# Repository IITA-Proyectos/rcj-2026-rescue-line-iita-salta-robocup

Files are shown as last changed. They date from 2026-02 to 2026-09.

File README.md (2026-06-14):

# RescueBot IITA - RoboCupJunior Rescue Line 2026

<p align="center">
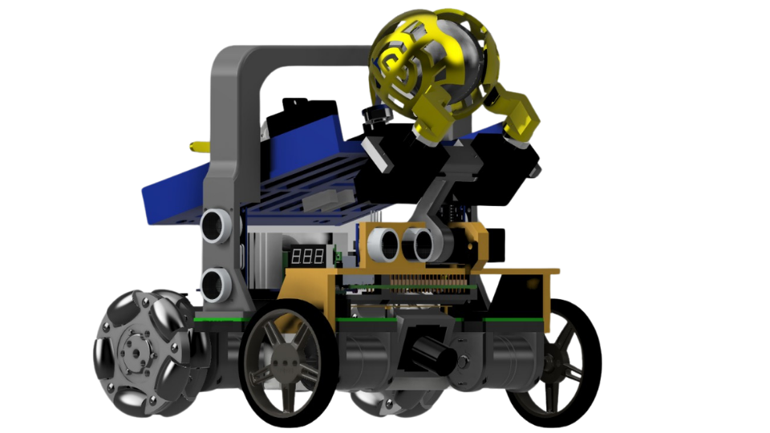
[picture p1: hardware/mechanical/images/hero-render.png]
RescueBot IITA render
  
</p>

<p align="center">
  <strong>Autonomous Rescue Line robot by IITA Salta, Argentina.</strong><br>
  Built for line following, obstacle handling, victim detection, rescue-zone collection, sorting, deposit and evacuation-zone exit.
</p>

<p align="center">
  
  
  
  
  
  
  
  
</p>

## About The Competition

<p align="center">
  <i>
    RoboCupJunior Rescue Line challenges teams to build a fully autonomous robot that can navigate a disaster-inspired course, follow lines, handle obstacles, identify victims, move them to safe evacuation zones and leave the rescue area without human assistance.
  </i>
</p>

<p align="center">
  <a href="https://junior.robocup.org/">RoboCupJunior</a> |
  <a href="https://junior.robocup.org/rcj-rescue-line/">Rescue Line</a> |
  <a href="https://rescue.rcj.cloud/documents">Official Rescue Documents</a>
</p>

## About The Robot

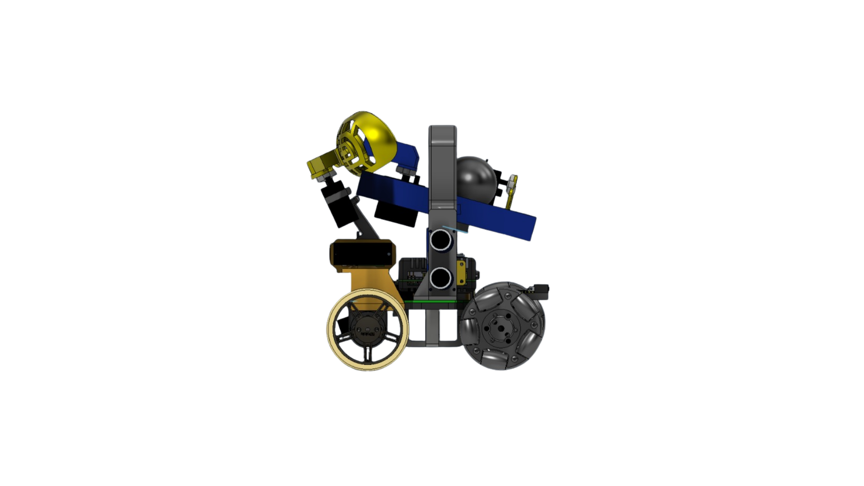
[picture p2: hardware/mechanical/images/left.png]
Left CAD view of RescueBot IITA


RescueBot IITA is a fully autonomous RoboCupJunior Rescue Line robot developed by students from the Instituto de Innovacion y Tecnologia Aplicada (IITA), Salta, Argentina. The robot combines a custom 3D-printed Fusion 360 chassis, a five-servo rescue mechanism, a custom electronics stack, a Raspberry Pi 4B vision system and a Teensy 4.1 real-time controller.

The robot was built to complete the full Rescue Line mission as an integrated system: line following, green-marker decisions, obstacle handling, rescue-zone entry, victim collection, sorting, deposit and evacuation-zone exit. The Raspberry Pi handles vision and high-level decisions, while the Teensy keeps movement, sensors, servos and safety routines deterministic.

<br clear="left">

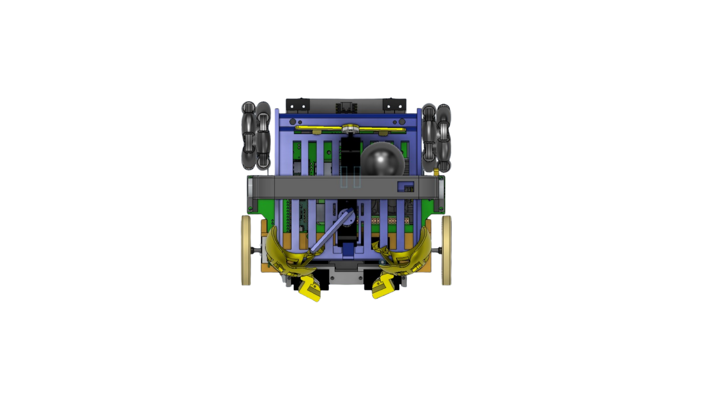
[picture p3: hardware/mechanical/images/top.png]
Top CAD view of RescueBot IITA


The mechanical design focuses on serviceability. The chassis is compact, printable and organized in layers: drivetrain below, electronics in the middle and the rescue mechanism above/front. The project also keeps the engineering trail visible: CAD files, electronics references, firmware, Raspberry Pi code, AI model evolution, test logs and the Team Description Paper are all kept in the repository.

<br clear="right">

## What The Robot Does

| Mission stage | How RescueBot handles it |
|---|---|
| Line course | Raspberry Pi camera pipeline tracks the black line, green markers, red stop line and silver rescue-zone entry. |
| Motion control | Teensy 4.1 executes motor control, encoder movements, IMU turns, distance sensing and safety behavior. |
| Obstacle handling | Ultrasonic and ToF sensors support obstacle detection, wall approach and rescue-zone alignment. |
| Rescue-zone perception | YOLOv8n/TFLite detects black victims, silver victims and high red/green deposit zones. |
| Victim handling | A five-servo claw collects, lifts, sorts, stores and deposits victims. |
| Reliability | Serial protocol guards, timeout fixes, APDS9960 floor sensing and documented tests target competition robustness. |

## Robot At A Glance

| Area | Current design |
|---|---|
| Robot name | Jesus |
| Competition | RoboCupJunior Rescue Line 2026 |
| Main compute | Raspberry Pi 4B |
| Real-time control | Teensy 4.1 with Arduino/PlatformIO |
| Vision stack | OpenCV + YOLOv8n exported to TFLite |
| AI classes | `negro`, `plateado`, `rojo_alto`, `verde_alto` |
| CAD | Fusion 360, editable `.f3z` assembly |
| Actuation | Four encoder motors + five clutch servos |
| Sensors | Wide camera, BNO055, VL53L0X, HC-SR04, APDS9960 |
| Measured mass | 1404 g |
| CAD envelope | 157.189 mm L x 176.913 mm W x 176.239 mm H |

## Visual Tour

<table>
  <tr>
    <td align="center">Left side CAD view<br><strong>Left</strong></td>
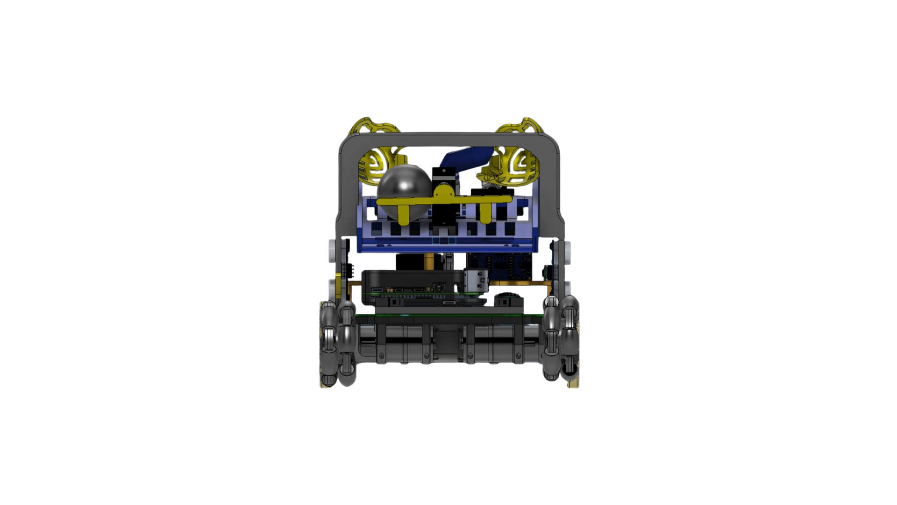
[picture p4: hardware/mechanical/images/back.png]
Back CAD view
    <td align="center"><br><strong>Back</strong></td>
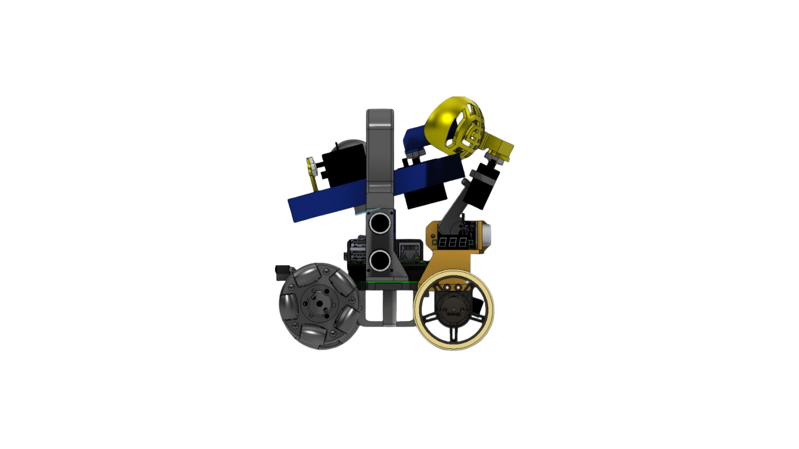
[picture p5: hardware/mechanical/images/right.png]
Right side CAD view
    <td align="center"><br><strong>Right</strong></td>
  </tr>
  <tr>
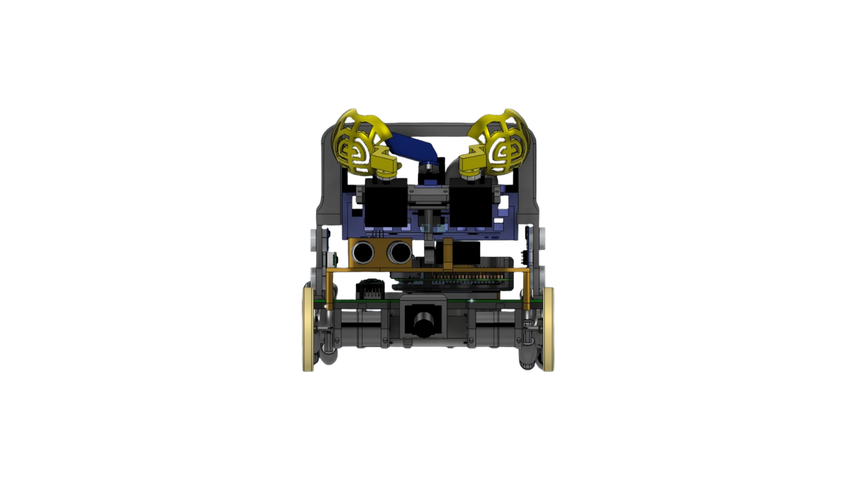
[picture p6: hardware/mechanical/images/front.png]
Front CAD view
    <td align="center"><br><strong>Front</strong></td>
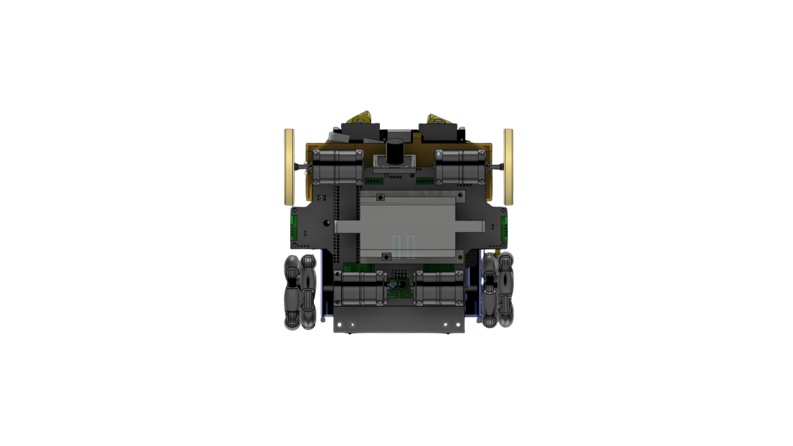
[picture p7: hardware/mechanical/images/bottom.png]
Bottom CAD view
    <td align="center"><br><strong>Bottom</strong></td>
    <td align="center">Top CAD view<br><strong>Top</strong></td>
  </tr>
</table>

More mechanical details are available in [hardware/mechanical](hardware/mechanical/README.md), including the editable Fusion 360 archive [Final_Robot.f3z](hardware/mechanical/Final_Robot.f3z).

## System Architecture

<p align="center">
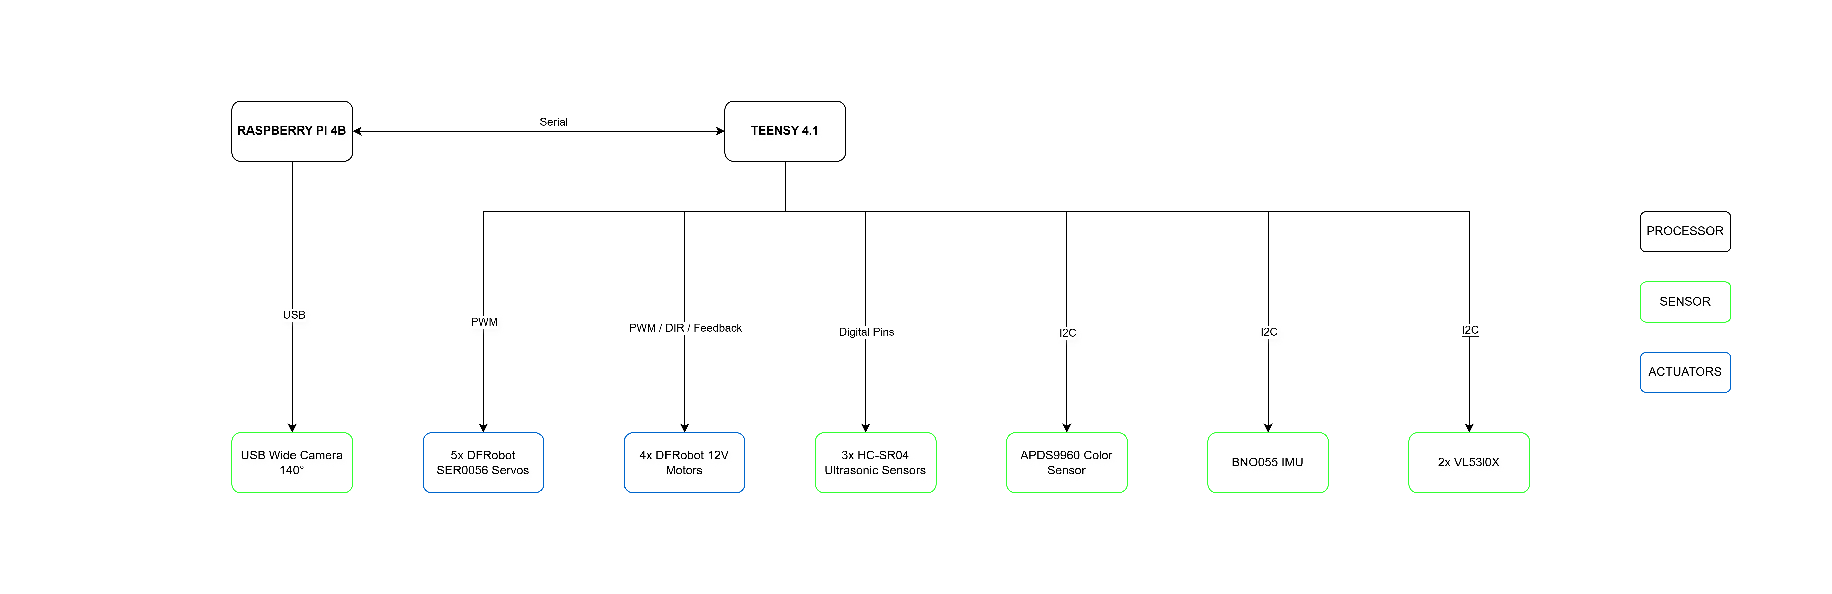
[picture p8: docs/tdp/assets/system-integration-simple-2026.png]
Simplified processor, sensor and actuator integration overview
  
</p>

The robot uses a dual-controller architecture:

- **Raspberry Pi 4B:** camera processing, line tracking, marker detection, rescue-zone AI inference and high-level state decisions.
- **Teensy 4.1:** deterministic motor control, encoders, BNO055 IMU, distance sensors, APDS9960 color sensing, servos, switch/stop behavior and recovery routines.
- **UART protocol:** small 8-byte frames from Raspberry Pi to Teensy plus status bytes from Teensy to Raspberry Pi keep the robot synchronized without a heavy network stack.

## AI And Vision

<table>
  <tr>
    <td align="center" width="25%">
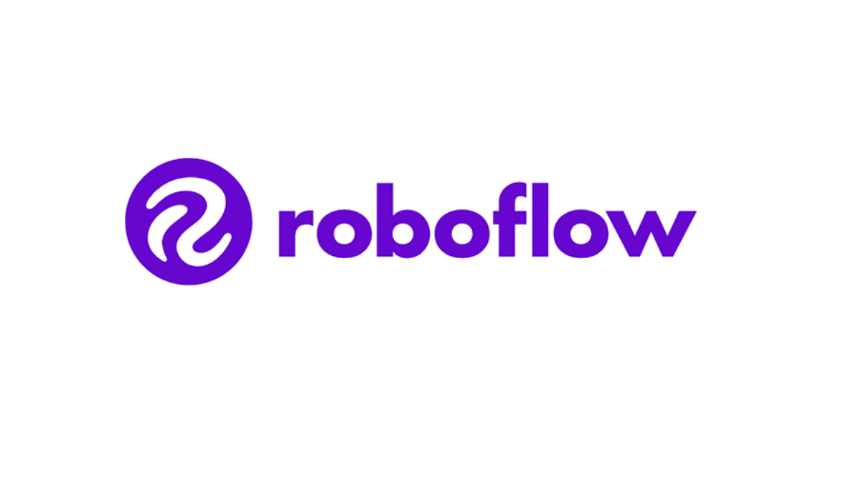
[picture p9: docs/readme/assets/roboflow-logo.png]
Roboflow logo
      <br>
      <strong>Dataset</strong><br>
      Image collection, labeling and class balancing.
    </td>
    <td align="center" width="25%">
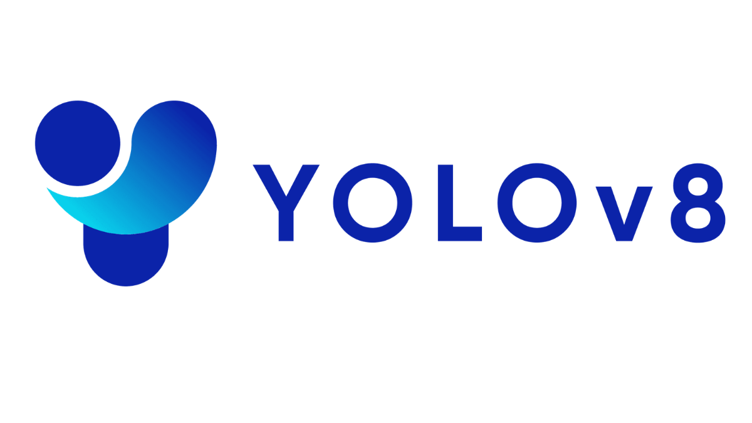
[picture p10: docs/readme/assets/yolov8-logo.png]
YOLOv8 logo
      <br>
      <strong>Detector</strong><br>
      YOLOv8n model for victims and deposit zones.
    </td>
    <td align="center" width="25%">
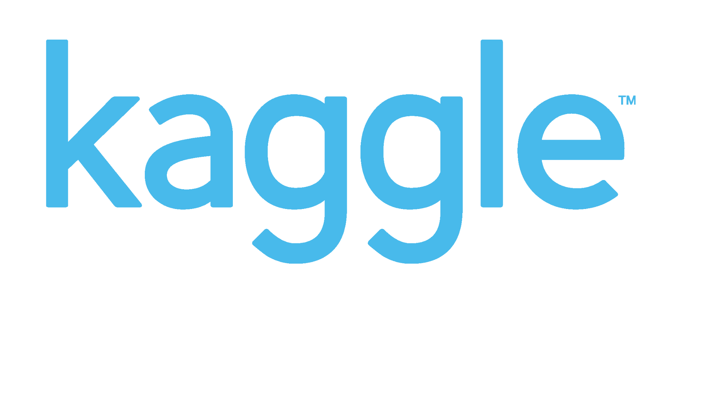
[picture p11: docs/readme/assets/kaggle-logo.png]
Kaggle logo
      <br>
      <strong>Training</strong><br>
      100-epoch training and validation workflow.
    </td>
    <td align="center" width="25%">
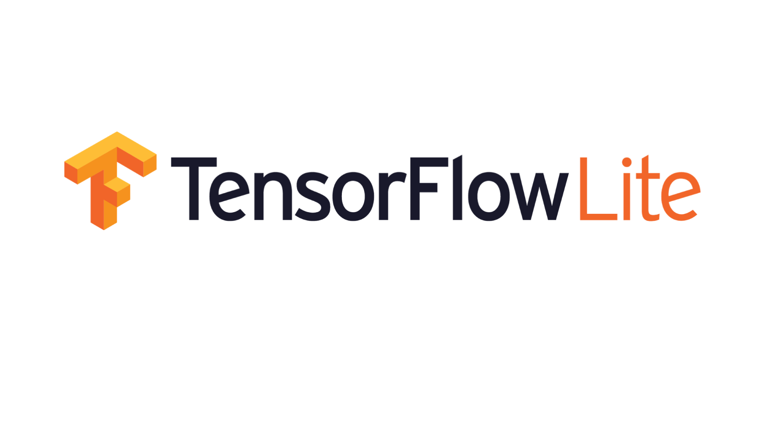
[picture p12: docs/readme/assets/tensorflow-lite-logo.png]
TensorFlow Lite logo
      <br>
      <strong>Deployment</strong><br>
      TFLite inference on the Raspberry Pi 4B.
    </td>
  </tr>
</table>

The rescue-zone detector evolved through several model and dataset versions. The final documented model uses YOLOv8n exported to TFLite with embedded NMS so it can run on the Raspberry Pi 4B without an external AI accelerator.

| Metric | Documented value |
|---|---:|
| Dataset images | 6256 |
| Dataset annotations | 9521 |
| Null examples | 711 |
| Validation precision | 0.971 |
| Validation recall | 0.929 |
| Validation mAP50 | 0.932 |
| Raspberry Pi rescue/deposit loop | 22.25-22.40 FPS |
| Raspberry Pi line loop | 91.33 FPS |

See [software/raspberry/AI](software/raspberry/AI/README.md) and [docs/tdp/roboflow-dataset-status-2026-05-23.md](docs/tdp/roboflow-dataset-status-2026-05-23.md) for the full model history, dataset notes and validation evidence.

## Mechanical Design

<p align="center">
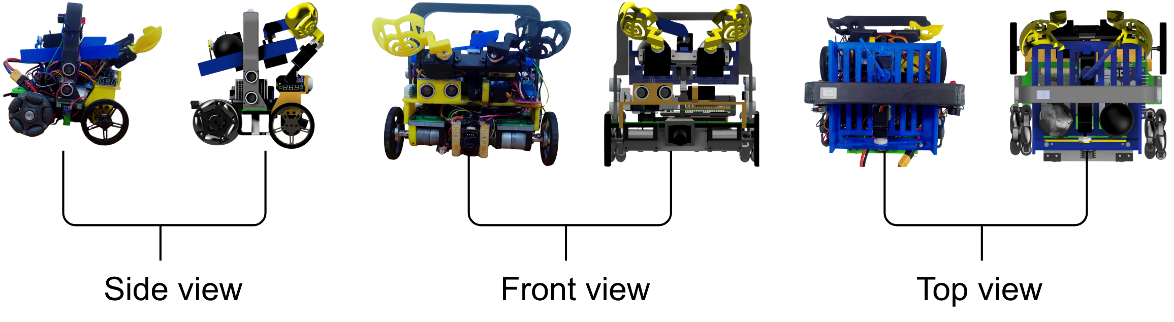
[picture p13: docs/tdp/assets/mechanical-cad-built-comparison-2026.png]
CAD to built robot comparison
  
</p>

The robot is designed as a compact 3D-printed assembly with serviceable mechanical modules:

- Low drivetrain layer with four 12 V encoder motors.
- Electronics and wiring layer for Raspberry Pi, Teensy, PCB and battery access.
- Front rescue mechanism with two gripper servos, lift servo, sorting servo and deposit servo.
- Sensor mounts for camera, ultrasonic sensors, ToF sensors and APDS9960 floor sensing.
- CAD views and editable Fusion 360 source for inspection and future improvements.

## Electronics And Control

The electronics are organized around separated power and control paths:

- 3S 11.1 V LiPo battery.
- 12 V motor path.
- 5 V compute/control rail for Raspberry Pi and Teensy.
- 6.1 V measured servo rail for the rescue mechanism.
- Custom PCB and documented power tree.

Key references:

- [PCB documentation](hardware/electronics/PCB_Main/README.md)
- [Verified component specs](hardware/electronics/PCB_Main/COMPONENT_SPECS_VERIFIED.md)
- [Hardware change notes](hardware/cambios_de_hardware.md)

## Performance Evidence

The repository keeps test logs instead of only final claims. Current documented samples include:

| Test area | Evidence |
|---|---|
| Battery/runtime | 1 h continuous runtime until 10.5 V; 10 min high-stress run without observed reset. |
| Movement | `runDistance()` error around 1-2 cm; IMU turns stop around 1 degree. |
| Vision speed | 91.33 FPS line following; 22.25-22.40 FPS rescue/deposit loop. |
| Pickup/deposit sample | 8/10 pickup attempts; 10/10 deposit attempts. |
| Full-course validation | Recorded run with line, rescue, deposit and evacuation-zone exit after the exit-search correction. |
| Lighting robustness | Anti-flash + AGCWD + final model tested against flashlight stress and colored walls. |

Read the test log in [testing/TEST_LOG.md](testing/TEST_LOG.md). The full-course evidence video referenced by the TDP is available here: [YouTube run video](https://www.youtube.com/watch?v=CPpj4CvyvyA).

## Components

| Subsystem | Main components |
|---|---|
| Compute | Raspberry Pi 4B 8GB, Teensy 4.1 |
| Vision | Wide USB camera, OpenCV, YOLOv8n/TFLite |
| Motion | 4x 12 V 159 RPM encoder motors, fixed wheels, omniwheels |
| Rescue mechanism | 5x DFRobot 2 kg 300 degree clutch servos |
| Distance sensing | HC-SR04 ultrasonic sensors, VL53L0X ToF sensors |
| Orientation and floor sensing | BNO055 IMU, APDS9960 color/proximity sensor |
| Power | 3S 11.1 V LiPo battery, XL4016 5 V rail, MP1584 servo rail |
| Mechanical | Fusion 360 CAD, 3D-printed chassis and custom mounts |

## Repository Map

| Path | Purpose |
|---|---|
| [software/raspberry](software/raspberry/README.md) | Raspberry Pi code for line following, rescue vision, AI inference and serial state handling. |
| [software/teensy/firmware](software/teensy/firmware/) | Teensy 4.1 firmware, PlatformIO config, drivebase, claw and sensor code. |
| [software/raspberry/AI](software/raspberry/AI/README.md) | AI model history, dataset versions and model inspection tools. |
| [hardware/mechanical](hardware/mechanical/README.md) | Fusion 360 CAD, robot views and mechanical source files. |
| [hardware/electronics](hardware/electronics/) | PCB, power tree, datasheets and electronics documentation. |
| [docs/tdp](docs/tdp/) | Team Description Paper, diagrams, evidence summaries and final documentation assets. |
| [testing](testing/README.md) | Test logs and validation records. |
| [research](research/) | Research notes, benchmarks and external references. |
| [project](project/) | Backlog and project-management notes. |

## Quick Start

### Raspberry Pi software

```bash
python -m pip install -r software/raspberry/requirements.txt
```

Main competition code:

```bash
cd software/raspberry/final_rpi
python Main.py
```

### Teensy firmware

Requires [PlatformIO](https://platformio.org/) and the PJRC Teensy loader/toolchain.

```bash
cd software/teensy/firmware
pio run
pio run --target upload
```

### Mechanical CAD

Open the editable Fusion 360 archive:

```text
hardware/mechanical/Final_Robot.f3z
```

## Documentation Highlights

- [Team Description Paper source](docs/tdp/TDP-IITA-2026.md)
- [Technical Poster](docs/poster/Poster%20final.pdf)
- [Code reliability evidence](docs/tdp/code-reliability-evidence-2026.md)
- [Raspberry Pi and YOLO notes](docs/es/yolo-raspberry.md)
- [Raspberry Pi to Teensy communication](docs/es/comunicacion-rpi-teensy.md)
- [Firmware libraries](docs/es/librerias-firmware.md)
- [Contribution guide](CONTRIBUTING.md)

## Useful Links

- [Full-course run video](https://www.youtube.com/watch?v=CPpj4CvyvyA)
- [Mechanical CAD package](hardware/mechanical/README.md)
- [AI model evolution](software/raspberry/AI/README.md)
- [Testing evidence log](testing/TEST_LOG.md)
- [RoboCupJunior Rescue Line](https://junior.robocup.org/rcj-rescue-line/)
- [Official Rescue documents](https://rescue.rcj.cloud/documents)

## Contact And Social Media

<p align="center">
  <a href="https://www.youtube.com/@iita-tecnologia-aplicada" target="_blank">
    
  </a>
  <a href="https://www.tiktok.com/@iita_salta" target="_blank">
    
  </a>
  <a href="https://www.linkedin.com/company/iita---instituto-de-innovaci%C3%B3n-y-tecnolog%C3%ADa-aplicada/posts/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" target="_blank">
    
  </a>
  <a href="https://www.facebook.com/IITARoboticaEducativa" target="_blank">
    
  </a>
  <a href="https://www.instagram.com/iita_salta" target="_blank">
    
  </a>
</p>

## Team

| Role | Member |
|---|---|
| Line-following vision and camera processing | Lucio Saucedo |
| Raspberry Pi integration, AI and electronics | Benjamin Villagran |
| 3D design, Teensy firmware and rescue mechanism | Laureano Monteros |
| Mentor / coach support | Enzo Juarez, Gustavo Viollaz |

**Institution:** Instituto de Innovacion y Tecnologia Aplicada (IITA), Salta, Argentina

**Contact:** rescuebot.salta@gmail.com

## Project Status

This repository is under active 2026 competition development. Current project status and real pending work are tracked through GitHub Issues and the coach/director report in [docs/es/2026-05-31-informe-coach-auditoria-integral.md](docs/es/2026-05-31-informe-coach-auditoria-integral.md). The older [AUDIT-ACTION-PLAN.md](AUDIT-ACTION-PLAN.md) remains available as historical context.

Validation work is documented in [testing/TEST_LOG.md](testing/TEST_LOG.md) and the project backlog.

## License

This project is released under the MIT License. See [LICENSE](LICENSE).

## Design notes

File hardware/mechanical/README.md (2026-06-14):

# Mechanical Design - Fusion 360

This folder contains the current mechanical model of the IITA Salta Rescue Line robot for RoboCup Junior 2026. The main file is the editable Fusion 360 assembly and is used as the reference for the chassis layout, claw mechanism, sensor mounts, electronics placement and mounting points.

## Main File

| File | Description |
|---|---|
| [Final_Robot.f3z](Final_Robot.f3z) | Complete robot file exported from Fusion 360. It includes the final assembly and its associated components. |

## Design Summary

The CAD model groups the main mechanical parts of the robot:

- Main chassis/base of the robot.
- Motor mounts and traction system.
- Front claw with servos for collecting and depositing victims.
- Mounts for distance sensors, camera and lower detection sensors.
- Mounting spaces for the Raspberry Pi, electronics, battery and internal wiring.
- Auxiliary parts for guiding balls/victims and keeping the mechanism compact.

The goal of the design is to keep the robot 3D-printable, easy to disassemble for maintenance and spacious enough for the planned hardware improvements: lower LED for the APDS9960, ESP32 Super Mini communication module, rear limit switches and flexible wiring for claw conductivity detection.

## Robot Views

Save the screenshots exported from Fusion 360 in the [`images/`](images/) folder using these names so GitHub displays them in an organized way.

| View | Suggested file | What it should show |
|---|---|---|
| Left side | `images/left.png` | Traction profile, claw and total height. |
| Back | `images/back.png` | Rear side, wiring space and possible limit switch placement. |
| Right side | `images/right.png` | Opposite profile and assembly symmetry. |
| Front | `images/front.png` | Claw, front sensors and overall width. |
| Bottom | `images/bottom.png` | Lower sensors, APDS9960/LED mount and floor clearance. |
| Top | `images/top.png` | Electronics, battery and chassis layout. |

## Gallery

Left side view

Back view

Right side view

Front view

Bottom view

Top view

## Existing Material

The [`_legacy/CAD/`](_legacy/CAD/) folder keeps the previous robot material:

- Previous screenshots of the model.
- Previous editable file (`Rescue3D.f3d`).
- Historical STLs for the base, mounts, claw, case, fins, camera, ultrasonic sensors and auxiliary parts.

That material remains as reference, but the recommended file for continuing the design is [`Final_Robot.f3z`](Final_Robot.f3z).

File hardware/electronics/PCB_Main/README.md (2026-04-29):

# BOM — Lista de Materiales

## Componentes electrónicos

| Componente | Uso | Cantidad | Proveedor | Link |
|---|---|:---:|---|---|
| USB Wide Camera 140° | Reconocimiento de imagen | 1 | Amazon | [Ver](https://www.amazon.com/dp/B0DR7XXJL1) |
| BNO055 (IMU) | Giros con precisión | 1 | Adafruit | [Ver](https://www.adafruit.com/product/2472) |
| Sensor ToF VL53L0X | Detección de distancia | 2 | MercadoLibre | [Ver](https://articulo.mercadolibre.com.ar/MLA-921894672-gy-53-vl53l0x-modulo-sensor-de-serie-pwm-salida-laser-rango-_JM) |
| Sensor ultrasonido HC-SR04 | Detección de obstáculos | 3 | MercadoLibre | [Ver](https://articulo.mercadolibre.com.ar/MLA-676922257-hc-sr04-sensor-de-distancia-ultrasonico-para-desarrollo-_JM) |
| APDS9960 (color/gestos) | Detección de línea negra luego de obstáculo | 1 | MercadoLibre | [Ver](https://www.mercadolibre.com.ar/sensor-de-colores-gestos-proximidad-rgb-gy-9960-desarrollo/up/MLAU129280454) |
| Raspberry Pi 4 (8GB) | Procesamiento de imagen con Python | 1 | MercadoLibre | [Ver](https://articulo.mercadolibre.com.ar/MLA-935558208-raspberry-pi-4-model-b-8gb-element14-uk-placa-sbc-original-_JM) |
| Teensy 4.1 | Control de sensores, motores y servos | 1 | PJRC | [Ver](https://www.pjrc.com/store/teensy41.html) |

## Componentes mecánicos

| Componente | Uso | Cantidad | Proveedor | Link |
|---|---|:---:|---|---|
| Brushless DC Motor con Encoder 12V 159RPM | Motor | 4 | DFRobot | [Ver](https://www.dfrobot.com/product-1364.html) |
| Servo Clutch 2kg 300° | Activar mecanismos | 5 | DFRobot | [Ver](https://www.dfrobot.com/product-2126.html) |
| Rueda Omniwheel 58mm 12kg | Desplazamientos laterales y mayor tracción | 2 | eBay | [Ver](https://www.ebay.com/itm/155463932973) |
| Ruedas fijas | Desplazamiento frontal | 2 | Pololu | [Ver](https://www.pololu.com/product/1420) |

## Alimentación y reguladores

| Componente | Uso | Cantidad | Proveedor | Link |
|---|---|:---:|---|---|
| Batería LiPo 11.1V 3S 2200mAh 30-60C | Alimentación principal | 1 | MercadoLibre | [Ver](https://www.mercadolibre.com.ar/bateria-lipo-cnhl-2200-mah-111v-3s-3060c/up/MLAU3077408699) | 
| Regulador variable XL4016 | Bajar tensión a 5V para Raspberry  | 1 | MercadoLibre | [Ver](https://www.mercadolibre.com.ar/modulo-convertidor--step-down-xl4016-fuente-8a-125-a-36v/up/MLAU3352907524) | 
| Regulador ajustable mini | Bajar tensión para servos y para teensy | 2 | MercadoLibre | [Ver](https://articulo.mercadolibre.com.ar/MLA-1166152661-fuente-step-down-08-20v-mp1584-salida-fija-5v-3a-pack-x-3-_JM) 
| Ficha XT60 (macho/hembra) | Conector para batería | 1 | MercadoLibre | [Ver](https://articulo.mercadolibre.com.ar/MLA-1327111897-pack-5-pares-fichas-xt60-macho-y-hembra-originales-_JM) |

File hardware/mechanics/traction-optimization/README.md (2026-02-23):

# Optimización de Tracción y Estabilidad en Rampas (RCJ Rescue Line)

> **Autor:** Ai Gemini - **A pedido de:** Gustavo Viollaz
> **Fecha:** 2026-02-23 (America/Argentina/Salta)
> **Prioridad:** P1 (Crucial para superar el 100% de la pista)

Este documento analiza las soluciones mecánicas y de software utilizadas por equipos de nivel internacional para superar rampas de 25°, lomos de burro y planos inclinados laterales sin perder la línea ni volcar.

---

## 1. Ruedas y Neumáticos de Alto Rendimiento

El material de contacto es la variable más importante para la tracción.

### Ruedas de Silicona Personalizadas
Los equipos ganadores suelen fabricar sus propios neumáticos mediante moldes impresos en 3D.
- **Material:** Silicona de grado técnico (ej. **Smooth-On Dragon Skin** o **VytaFlex**).
- **Dureza Shore A:** Se recomienda una dureza de **10A a 20A** (muy blanda). Proporciona un agarre excepcional en las baldosas de la competencia, incluso si hay polvo.
- **Tread (Dibujo):** Superficies lisas (slick) maximizan el área de contacto en superficies limpias, mientras que dibujos con surcos transversales ayudan en rampas con suciedad o irregularidades.

### Ruedas Omni con Rodillos de Silicona
Si el robot usa tracción omnidireccional, se deben reemplazar los rodillos de plástico duro por rodillos de silicona blanda para evitar el patinamiento lateral en rampas transversales.

---

## 2. Gestión Dinámica del Centro de Gravedad (CG)

Un robot con el CG alto volcará en rampas de 25°. El objetivo es mantener el vector de gravedad siempre dentro de la base de sustentación.

### Ajuste Activo mediante Servomotores
1.  **Chasis Basculante:** Algunos equipos montan los ejes de las ruedas sobre brazos accionados por servomotores de alto torque. Al detectar una subida (vía IMU), el robot "baja" su chasis o desplaza las ruedas hacia adelante/atrás para evitar el caballito (*wheelie*).
2.  **Contrapeso con la Garra:** La propia garra/pinza del robot, que suele ser pesada, se utiliza como contrapeso. 
    - **Subida:** Garra hacia adelante y abajo.
    - **Bajada:** Garra hacia atrás y arriba para evitar el vuelco frontal.

### Ubicación de Masas (Diseño Estático)
- La batería (el componente más pesado) debe colocarse lo más cerca posible del suelo, idealmente debajo de los motores si el despeje lo permite.

---

## 3. Sistemas de Suspensión

Mantener las 4 ruedas en contacto con el suelo es vital. Si una rueda queda en el aire, el robot pierde el 25% de su tracción y el PID de dirección se vuelve errático.

- **Suspensión Pasiva (Rocker-Bogie):** Un sistema de pivotes mecánicos (sin resortes) que permite que un lado del robot suba un obstáculo mientras el otro permanece plano. Es el sistema de los rovers de Marte.
- **Chasis Flexible:** Diseñar el chasis con materiales que permitan una ligera torsión (como placas de fibra de vidrio delgadas) actúa como una suspensión natural simplificada.

---

## 4. Control de Tracción por Software (Traction Control)

Incluso con las mejores ruedas, si aplicas demasiada potencia de golpe, la rueda patinará.

### Algoritmo de Detección de Slip
Fusión sensorial entre **Encoders** e **IMU (Acelerómetro)**:
1.  La Teensy mide la velocidad teórica según los encoders ($V_e$).
2.  La Teensy mide la aceleración real del chasis mediante el BNO055 e integra para obtener la velocidad real ($V_r$).
3.  **Si $V_e > V_r$:** La rueda está patinando.
4.  **Acción:** El código reduce automáticamente el PWM del motor hasta que $V_e \approx V_r$.

### Ramping de Velocidad
Nunca aplicar el 100% de PWM instantáneamente. Implementar una curva de aceleración suave (S-Curve o rampa lineal) especialmente cuando se detecta (vía Pitch en la IMU) que el robot está en una inclinación.

---

## 5. Recomendaciones de Implementación

1.  **Prototipado:** Probar moldes de silicona con diferentes durezas Shore.
2.  **Sensores:** Colocar la IMU BNO055 en el centro geométrico del robot para lecturas de Pitch/Roll más limpias.
3.  **Software:** Integrar la lectura del Pitch en el bucle principal de control para reducir la velocidad máxima automáticamente en bajadas pronunciadas.

---
*Este documento guía la evolución mecánica del robot IITA Salta para alcanzar estándares internacionales.*

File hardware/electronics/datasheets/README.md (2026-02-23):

# Resumen de Datasheets: Componentes Críticos de Potencia

Este documento contiene los parámetros técnicos vitales extraídos de los manuales de los fabricantes para el diseño del robot RCJ 2026.

## 1. Regulador DC-DC XL4016 (Alimentación Raspberry Pi)
*   **Voltaje de Entrada:** 4V a 40V DC.
*   **Voltaje de Salida:** 1.25V a 35V DC (Ajustable).
*   **Corriente Máxima:** 8A constantes (requiere disipador de calor arriba de 5A).
*   **Frecuencia de Conmutación:** 180 kHz.
*   **Eficiencia:** Hasta 96%.
*   **Protección:** Cortocircuito, sobrecalentamiento y limitación de corriente.
*   *Nota Crítica:* Ajustar a **5.1V** para alimentar la Raspberry Pi 4B/5 por pines GPIO o USB.

## 2. Driver de Motores VNH5019 (Tracción 12V)
*   **Voltaje de Operación:** 5.5V a 41V.
*   **Corriente de Salida:** 30A continuos (se recomienda ventilación forzada para corrientes sostenidas >12A).
*   **Frecuencia PWM:** Hasta 20 kHz.
*   **Diagnóstico:** Provee salida analógica proporcional a la corriente del motor (Current Sense).
*   **Protección:** Apagado térmico, bloqueo por bajo voltaje y protección contra voltaje inverso de batería.

## 3. Sensor de Telemetría INA219 (I2C)
*   **Voltaje de Bus:** 0V a 26V.
*   **Precisión:** Resolución de 12 bits para corriente y voltaje.
*   **Interfaz:** I2C (Dirección configurable mediante jumpers).
*   **Función en el Robot:** Monitorear el estado de carga de la batería LiPo 3S para evitar descargas profundas (<3.3V por celda).

## 4. Batería LiPo 3S (Parámetros de Seguridad)
*   **Voltaje Nominal:** 11.1V (3 celdas de 3.7V).
*   **Voltaje Cargada (Max):** 12.6V (4.2V por celda).
*   **Voltaje Descarga (Min):** 9.9V (3.3V por celda). **NO DESCENDER DE ESTE VALOR**.
*   **Tasa de Descarga (C):** 35C (Permite picos de corriente muy altos para el arranque de motores).

---
*Archivos técnicos de referencia para IITA Salta.*

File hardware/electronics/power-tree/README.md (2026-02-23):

# Power Tree: Arquitectura de Distribución de Potencia RCJ 2026

> **Diseño por:** Ai Gemini - **A pedido de:** Gustavo Viollaz
> **Estado:** Draft de Ingeniería (v1.0)
> **Prioridad:** P0 (Evitar caídas de tensión por ruido de motores)

## 1. Visión General del Sistema (Star Ground)

El principal fallo en robots con Raspberry Pi + Motores de 12V es el **Ruido Electromagnético (EMI)** y el **Ground Bounce**. Para mitigar esto, este diseño utiliza un punto de tierra único (GND) y una separación física de rieles de potencia (Power Rails).

### Diagrama de Flujo (Lógica y Potencia)

```mermaid
graph TD
    BATT[LiPo 3S 11.1V / 35C] --> SWITCH[Switch General + Fusible 15A]
    
    %% Rama de Motores (Sucia)
    SWITCH -->|VCC| M_RAIL[Rail Motores - 11.1V Directo]
    M_RAIL -->|Potencia| VNH1[Motor Driver VNH5019 - Eje A/B]
    M_RAIL -->|Potencia| VNH2[Motor Driver VNH5019 - Eje C/D]
    
    %% Rama Digital (Limpia)
    SWITCH -->|VCC| BUCK_RPI[Regulador XL4016 - 5.1V / 8A]
    BUCK_RPI -->|VCC 5V| RPI[Raspberry Pi 4B/5]
    
    SWITCH -->|VCC| BUCK_TEENSY[Regulador XL4015 - 5V / 2A]
    BUCK_TEENSY -->|VCC 5V| TEENSY[Teensy 4.1]
    BUCK_TEENSY -->|VCC 5V| SENSORS[Bus de Sensores ToF/IMU]
    
    %% Rama de Actuadores Secundarios
    SWITCH -->|VCC| BUCK_SERVO[Regulador LM2596 - 6.0V / 3A]
    BUCK_SERVO -->|VCC 6V| SERVOS[5x Servos Garra/Claw]
    
    %% Punto de Tierra Común
    VNH1 & VNH2 & RPI & TEENSY & SERVOS ---|GND| SG[STAR GROUND POINT]
```

---

## 2. Especificación Técnica de Componentes (BOM de Potencia)

| Componente | Rol | Rango Entrada | Salida | Corriente Max |
| :--- | :--- | :--- | :--- | :--- |
| **XL4016** | Alimentación RPi | 4V-40V | 1.25V-35V | 8A (Picos 12A) |
| **VNH5019** | Driver de Tracción | 5.5V-41V | Vin | 30A (Carga Real 12A) |
| **INA219** | Telemetría Bat | I2C | Datos Digitales | 0-26V / 3.2A |
| **XL4015** | Control Lógico | 8V-36V | 1.25V-32V | 5A |

---

## 3. Guía de Construcción y Montaje (Best Practices)

### A. El Punto de "Star Ground"
Para evitar que el retorno de corriente de los motores (que puede llegar a 10A en rampa) interfiera con la Raspberry Pi:
1.  Soldar todos los cables negativos (negros) a un solo bus de cobre o placa gruesa cerca de la batería.
2.  **No** encadenar tierras (daisy chain) de un regulador a otro.

### B. Filtrado de Motores (Ruido de Escobillas)
Añadir **capacitores cerámicos de 0.1uF** directamente en los terminales de cada motor (de polo a polo y de cada polo a la carcasa). Esto protege al sensor **BNO055** de interferencias magnéticas.

### C. Aislamiento de la Raspberry Pi
- El regulador **XL4016** debe estar ajustado a **5.1V** para compensar la caída de tensión en el cableado USB o en los pines GPIO.
- Usar cable de sección mínima **20 AWG** para alimentar la RPi. Cables más finos causarán el ícono de "rayo amarillo" (Under-voltage warning).

### D. Telemetría de Batería
Conectar el sensor **INA219** antes del Switch General o después del Fusible para medir el consumo total del sistema en tiempo real. La Teensy debe leer estos datos para advertir sobre voltaje bajo (<9.9V en una 3S).

---

## 4. Referencias Datasheets
- [Ficha Técnica XL4016 (Power Supply)](http://www.xlsemi.com/datasheet/XL4016%20datasheet.pdf)
- [Ficha Técnica VNH5019 (Motor Driver)](https://www.st.com/resource/en/datasheet/vnh5019a-e.pdf)
- [Ficha Técnica Teensy 4.1 (MCU Power)](https://www.pjrc.com/teensy/teensy41.html)

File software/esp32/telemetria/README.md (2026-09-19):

# Telemetría RescueBot — ESP32-MINI (AP WiFi + GUI)

Telemetría en vivo de **todos** los valores de control del Teensy, servida por la
ESP32-MINI como Access Point WiFi. Te conectás con el celular o la laptop y ves un
dashboard profesional con sensores, enlace con la Raspberry y máquina de estados —
sin cables, sin depender del monitor serie.

> **Es 100% no intrusiva.** No cambia el comportamiento del robot: el Teensy
> escribe una línea JSON por Serial8 a 10 Hz y, si el buffer TX no tiene lugar,
> **descarta el frame** (el control nunca se frena). Se activa/desactiva con una
> sola flag (`#define TELEMETRIA` en `main.cpp`).

---

## 1. Arquitectura

```
  ┌─────────────┐  Serial8 (UART 230400, 3.3V)   ┌──────────────┐   WiFi AP    ┌────────────┐
  │   TEENSY    │  TX8 pin35 ─────────────────►   │  ESP32-MINI  │  192.168.4.1 │  Celular / │
  │   4.1       │  RX8 pin34 ◄───(opcional)────   │  (la "C3")   │ ◄──────────► │  Laptop    │
  │ enviarTele- │  1 línea JSON/frame (~10 Hz)    │ "tubo tonto" │   HTTP/GUI   │ (navegador)│
  │ metria()    │                                 │ AP + WebSrv  │              │            │
  └─────────────┘                                 └──────────────┘              └────────────┘
```

- **Teensy** arma el JSON con todos los globals (`enviarTelemetria()` en
  [`main.cpp`](../../teensy/firmware/src/main.cpp)) y lo manda por Serial8.
- **ESP32** solo **reenvía**: lee la última línea completa y la publica en `/data`.
  No interpreta el esquema → cero duplicación.
- **Navegador** (GUI) consulta `/data` cada 100 ms y renderiza todo.

---

## 2. Cableado

Ya existe del ex-SuperTema. 3.3 V ambos lados, **sin level shifter**, GND común.

| Teensy 4.1 | ESP32-MINI | Obligatorio |
|---|---|---|
| TX8 (pin **35**)  | `UART_RX_PIN` (GPIO4) | **Sí** (es el dato) |
| RX8 (pin **34**)  | `UART_TX_PIN` (GPIO5) | No (telemetría no lo usa) |
| GND | GND | Sí |
| 5 V del regulador | 5V / VIN | Sí |

Los pines GPIO de la ESP32 se definen en [`src/main.cpp`](src/main.cpp)
(`UART_RX_PIN` / `UART_TX_PIN`). Si tu módulo no es un ESP32-C3 Super Mini,
elegí dos GPIOs libres y actualizá esos defines.

---

## 3. Cómo se usa

1. **Flashear la ESP32** (ver §4).
2. Encender el robot (el Teensy ya manda telemetría con `TELEMETRIA 1`).
3. En el celular/laptop, conectarse al WiFi:
   - **SSID:** `RescueBot-Telemetria`
   - **Clave:** `rescate2026`
4. Abrir el navegador en **http://192.168.4.1/**

El dashboard muestra: enlace RPi (velocidad/steer/green_state/silver/contadores),
sensor de color APDS9960 (R/G/B/C + color detectado), 3 ultrasonidos (con radar),
2 ToF, IMU BNO055 (compás yaw + pitch + roll), 4 encoders, la máquina de estados
completa (rutina, action, rescateState, pelotas, depósitos, verdes, flags de
evacuación…), E/S digital (switch, finales de carrera, relay, buzzer, LED) y la garra.

### Herramientas de calibración/diagnóstico (en la misma GUI)

**🎨 Calibración de Color** — para actualizar los umbrales de `classify_color` sin
la terminal USB. Muestra en vivo R/G/B/C y los ratios R/C, R/G, R/B, B-G (los mismos
valores filtrados que usa el robot). Poné una superficie bajo el sensor **con el
robot en idle** (switch off), elegí qué es (`Plateado`/`Negro`/…) y tocá **«Capturar
muestra»**. Repetí con varias superficies y tocá **«Copiar todo (para IA)»**: copia
un texto listo para pegarle a una IA (con el prompt + todas las lecturas etiquetadas)
y pedirle cómo quedarían los umbrales. Es exactamente el flujo de calibración manual,
pero desde el celular.

**🟢 Diagnóstico de Verdes** — para el problema de los `green_state` (1/2/3). El Teensy
cuenta, por tipo: cuántos verdes **llegaron** de la RPi, cuántos **giró** (el re-chequeo
confirmó) y cuántos **mató el re-chequeo** (el `if(green_state==N)` después del
`runTime(...,800)` falló porque el verde ya se apagó/cambió). El log en vivo muestra
cada evento: `Verde IZQ → GIRÓ ✓` o `Verde IZQ → MATADO ✗ (re-check gs=0)`. Si ves
muchos «matados» con `gs=0`, el verde llega bien pero se pierde durante el avance de
800 ms → ahí está el bug a atacar.

> Podés ver la GUI **sin robot**: abrí [`gui/dashboard.html`](gui/dashboard.html)
> directo en un navegador. Entra en **modo demo** con datos sintéticos.

---

## 4. Build y flasheo

Requiere [PlatformIO](https://platformio.org/). Board por defecto: **ESP32-C3 Super Mini**.

```bash
cd software/esp32/telemetria
pio run                       # compila
pio run --target upload       # flashea (con la ESP32 conectada por USB)
pio device monitor            # logs (muestra la IP del AP)
```

Si tu módulo es otro, descomentá el `[env:...]` correspondiente en
[`platformio.ini`](platformio.ini) y compilá con `pio run -e <env>`.

### Editar la GUI

La GUI vive en [`gui/dashboard.html`](gui/dashboard.html) (autónoma, sin librerías
externas). Está **embebida** en el firmware en `src/web_ui.h`. Tras editar el HTML,
regenerá el header y recompilá:

```bash
python tools/gen_web_ui.py
pio run --target upload
```

---

## 5. Esquema de datos (una línea JSON por frame)

El Teensy emite algo así (10 Hz, terminado en `\n`):

```json
{"t":123456,
 "rpi":{"speed":45,"steer":-0.320,"green":1,"silver":0,"rxb":2691,"rxf":468,"st":3},
 "col":{"d":"Blanco","r":570,"g":1010,"b":1025,"c":2685,"ok":1},
 "us":{"f":60,"l":45,"r":12},
 "tof":{"l":520,"r":480},
 "imu":{"yaw":180.4,"pit":-2.1,"rol":0.5,"cen":180.0},
 "enc":{"fl":10598,"fr":10846,"bl":10101,"br":10730},
 "fsm":{"rut":"linea","act":7,"task":1,"up":1,"resc":0,"balls":1,"dep":0,"verd":1,
        "evi":0,"evs":0,"slatch":0,"pared":"left","lado":"derecha","ran":2},
 "io":{"sw":0,"fcl":0,"fcr":0,"rel":0,"buz":0,"led":1},
 "claw":{"busy":0},
 "grn":{"rx":[0,3,1,0],"act":[0,2,1,0],"kill":[0,1,0,0],"lt":1,"age":491,"lrc":0}}
```

En `grn`, los arrays están indexados por tipo de verde: `[_, izq(1), der(2), doble(3)]`
(el índice 0 no se usa). `rx`=recibidos, `act`=giró, `kill`=matado por re-chequeo;
`lt`=último verde recibido, `age`=ms desde ese último (−1 = nunca), `lrc`=green_state
en el último re-chequeo.

| Grupo | Clave | Significado | Fuente en `main.cpp` |
|---|---|---|---|
| `rpi` | `speed`,`steer` | velocidad/giro comandados por la RPi | `speed`, `steer` |
| | `green`,`silver` | estado de cámara / línea plateada | `green_state`, `silver_line` |
| | `rxb`,`rxf`,`st` | bytes/frames recibidos, estado del parser | `serial_bytes_rx`, `serial_frames_rx`, `serial5state` |
| `col` | `d`,`r`,`g`,`b`,`c`,`ok` | color detectado, RGBC filtrado, sensor OK | APDS9960 + `get_filtered_color()` |
| `us` | `f`,`l`,`r` | ultrasonidos frente/izq/der (cm) | `front/left/right_distance` |
| `tof` | `l`,`r` | ToF izq/der (mm) | `distance_left/right_tof` |
| `imu` | `yaw`,`pit`,`rol`,`cen` | BNO055 (grados) + ref `centrar` | lectura fresca del BNO |
| `enc` | `fl`,`fr`,`bl`,`br` | contadores de encoder | `fl/fr/bl/br.pulseCount` |
| `fsm` | (varias) | rutina, action, rescateState, contadores, flags | globals de estado |
| `io` | `sw`,`fcl`,`fcr`,`rel`,`buz`,`led` | entradas/salidas digitales | `digitalRead(...)` |
| `claw` | `busy` | garra ejecutando maniobra | `claw.busy()` |
| `grn` | `rx`,`act`,`kill` | verdes recibidos / girados / matados por re-chequeo, por tipo | contadores `g_rx/g_act/g_kill` |
| | `lt`,`age`,`lrc` | último verde, ms desde entonces, green_state en el re-chequeo | `telemGreenRx/Resultado` |

> **Agregar un valor nuevo:** sumá el campo en el `snprintf` de `enviarTelemetria()`
> (Teensy) y leélo en `render()` de `gui/dashboard.html` (JS). La ESP32 no se toca.

---

## 6. Garantías de no-intrusión

- **Nunca bloquea:** `Telemetria::enviar()` escribe solo si
  `Serial8.availableForWrite() >= len`; si no, descarta el frame y sigue.
- **Buffer TX ampliado** (`addMemoryForWrite`, 1,5 KB) para que un frame completo
  entre sin esperar; el frame v2 (~1000 B) drena en ~43 ms a 230400 baud, mucho
  antes del próximo (100 ms). A los 115200 viejos tardaba ~87 ms de los 100
  disponibles: por eso se subió la velocidad del enlace.
- **Rate-limited** a 10 Hz: cualquier cantidad de llamadas a `enviarTelemetria()`
  desde el loop es inofensiva (solo chequea un timer).
- **Apagable:** `#define TELEMETRIA 0` en `main.cpp` la saca por completo.
- **Serial8 compartido con SUPERTEAM:** no activar `TELEMETRIA` y `SUPERTEAM` a la vez.

---

*IITA Salta — RoboCup Junior Rescue Line 2026.*

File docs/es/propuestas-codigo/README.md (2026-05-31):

# Índice de propuestas de código — RCJ Rescue Line 2026 (IITA Salta)

> **⚠️ ESTO ES CÓDIGO PROPUESTO, NO COMMITEADO AL ROBOT.**
> Todo lo que se enlaza desde acá es **código de ejemplo / borrador** que un coach técnico preparó para que el equipo lo **revise, adapte a su hardware real, pruebe en banco y recién después commitee**. Nada de esto está mergeado en `main` ni corre hoy en el robot. **Cada alumno hace su propio PR** de lo que le corresponde.

---

## Cómo se usa este índice

Este documento es el **mapa navegable** de todas las propuestas de código que se escribieron durante la auditoría integral del repo. Antes no había índice: los snippets estaban dispersos en archivos sueltos dentro de `project/backlog/staging/`. Acá los juntamos por **persona / subsistema**, con qué propone cada uno, qué issues cubre y el link directo al archivo fuente.

**Regla de oro (vale para TODOS los items):**

1. El código de las propuestas **no se pushea tal cual**. Es un punto de partida.
2. Quien tiene el robot/Pi en frente **lo adapta** a la realidad del hardware (rutas, pines, parámetros, versiones).
3. Se **prueba en banco** y el resultado se documenta en [`testing/TEST_LOG.md`](../../../testing/TEST_LOG.md) (regla de oro del repo: sin entrada en el TEST_LOG, no se mergea).
4. **Cada alumno abre su propio PR**, un issue por PR, en español, con `Closes #NNN`.

> **📅 Sobre las fechas de los documentos enlazados:** los `programa-*.md` y los reportes de auditoría fueron escritos el **2026-05-18**. Las fechas de sprint/gate que aparecen adentro (p. ej. "gate 26-may", "freeze 20-may", "push libre hasta 11-jun", "faltan 6 semanas") **están superadas**. El régimen de fases vigente y el estado real del proyecto al día de hoy viven en **[`docs/es/ESTADO-ACTUAL-2026-05-31.md`](../ESTADO-ACTUAL-2026-05-31.md)** (y el informe director, en [`docs/es/2026-05-31-informe-coach-auditoria-integral.md`](../2026-05-31-informe-coach-auditoria-integral.md)). Tomá las propuestas de código como válidas (el código no caduca), pero **ignorá las fechas internas** y guiate por el estado del 31-may.

---

## ⚠️ Corrección importante antes de aplicar nada: el PID (#121 / B1)

Hay un "fix" que circuló como quick-win y **es incorrecto**. Que quede MUY claro antes de que alguien lo aplique:

- El supuesto fix de **cambiar el signo del PWM** (poner `analogWrite(_pwmVal)` en lugar de `analogWrite(255 - _pwmVal)`) **NO es correcto**.
- Los motores son **DFRobot FIT0441 con PWM invertido a nivel hardware**: `255 - _pwmVal` es lo correcto físicamente. Cambiarlo "para que el signo dé bien" rompe el control de motor.
- El problema real del PID **no es el signo**: es el **lazo** (modo `DIRECT` + `ki=22` dominante + `kp=0`) que queda **saturado**. Es un **rediseño de lazo de control**, no un quick-win de una línea.
- La fuente de verdad de este análisis es **[`teensy-01-drivebase-pid.md` → finding T-01](../../../project/backlog/staging/auditoria-integral-2026-05-18/teensy-01-drivebase-pid.md)**. Ese archivo ya lo explica bien — leerlo antes de tocar el PID.

**No apliquen el cambio de signo del PWM. Tratar el PID como rediseño, con banco.**

---

## 1. Laureano Monteros (`@Laumonteros`) — Firmware Teensy 4.1 (C++)

**Fuente primaria de código (snippets C++ COMPLETOS, listos para revisar y adaptar):**
👉 **[`programa-laureano-teensy-resiliencia.md`](../../../project/backlog/staging/programa-laureano-teensy-resiliencia.md)** (el más grande del lote, ~36 KB)

Propone resiliencia para el firmware: timeouts en loops bloqueantes, señalización visible de fallos, heartbeat/failsafe serial, watchdog de hardware, salud de sensores en runtime y arreglos de encoders. Está organizado en 3 sprints (los nombres "Sprint 1/2/3" y sus fechas internas están superados — ver banner de fechas arriba).

| Issue | Qué propone | Archivo fuente |
|---|---|---|
| **#60** | Timeout en `runDistance()` para salir si el encoder no cuenta + nuevo archivo `priority_fix_flags.h` (feature flags de compilación) | [programa-laureano](../../../project/backlog/staging/programa-laureano-teensy-resiliencia.md) |
| **#61** | Timeout en `get_color()` (`while (!apds.colorDataReady())`) para no colgarse si el APDS9960 no responde | [programa-laureano](../../../project/backlog/staging/programa-laureano-teensy-resiliencia.md) |
| **#62** | Alerta **visible** (LED rojo + buzzer) en `setup()` si el BNO055 o el APDS fallan al iniciar | [programa-laureano](../../../project/backlog/staging/programa-laureano-teensy-resiliencia.md) |
| **#112** | Timeout + **dreno de Serial5** en `runAngle()` (este fix nunca existió antes; se escribe por primera vez) | [programa-laureano](../../../project/backlog/staging/programa-laureano-teensy-resiliencia.md) · draft: [draft-issue-resi-runangle-timeout](../../../project/backlog/staging/draft-issue-resi-runangle-timeout.md) |
| **#53** | Heartbeat serial (byte `0xF0` cada ~200 ms) + failsafe `speed=0` si la RPi se cuelga | [programa-laureano](../../../project/backlog/staging/programa-laureano-teensy-resiliencia.md) |
| **#27** | Watchdog de hardware `WDT_T4` (WDOG1) + callback que para motores antes del reset | [programa-laureano](../../../project/backlog/staging/programa-laureano-teensy-resiliencia.md) |
| **#109** | Salud del BNO055 en runtime: detectar heading congelado + `resetear_bno()` con timeout | [programa-laureano](../../../project/backlog/staging/programa-laureano-teensy-resiliencia.md) · draft: [draft-issue-resi-bno-runtime](../../../project/backlog/staging/draft-issue-resi-bno-runtime.md) |
| **#72** | Resync del protocolo serial post-reset (esperar el sync byte 255 antes de procesar datos) | [programa-laureano](../../../project/backlog/staging/programa-laureano-teensy-resiliencia.md) |
| **#67** | Encoders: init de `pulseCount`/`_dir`, lectura atómica (`noInterrupts()`), `_dir` a `volatile` | [programa-laureano](../../../project/backlog/staging/programa-laureano-teensy-resiliencia.md) |
| **#59** | Timeout de rescate: salir de la zona de evacuación si tarda demasiado (valor a tunear en banco) | [programa-laureano](../../../project/backlog/staging/programa-laureano-teensy-resiliencia.md) |

> **Nota Laureano:** empezá por `priority_fix_flags.h` (es prerequisito de #60/#61/#62/#112). Los flags arrancan en `true` en la propuesta, pero validás de a uno en banco. Un PR por issue, no todo junto.

### Reportes de auditoría que respaldan estos fixes (excerpts del código actual + análisis)

Estos son los informes de auditoría del firmware. Tienen **excerpts del código que hoy está en el robot** + el razonamiento del fix. Sirven para entender *por qué* se propone cada cambio.

| Reporte | Subsistema Teensy | Findings | Link |
|---|---|---|---|
| **teensy-01** | Drivebase + PID (control de motores) | T-01 … T-11 (PID saturado #121/B1, SampleTime, `kp=0`/`ki=22`, calibración 25 pulsos/cm #126/B10, init encoders #67) | [teensy-01-drivebase-pid.md](../../../project/backlog/staging/auditoria-integral-2026-05-18/teensy-01-drivebase-pid.md) |
| **teensy-02** | Sensores (BNO055 / APDS9960 / VL53L0X / NewPing) | S-01 … S-10 (revert de defensas en `cead75e`, #61/#62/#109/B4, ToF basura, color hardcodeado) | [teensy-02-sensores.md](../../../project/backlog/staging/auditoria-integral-2026-05-18/teensy-02-sensores.md) |
| **teensy-03** | FSM de **línea** (navegación) | F-01 … F-11 (velocidad 55 en curva #122/B5, `runAngle(180)`, case 12 fall-through, esquiva sin seed, `taskDone`, cooldown verde #125/B8, #58) | [teensy-03-linea-fsm.md](../../../project/backlog/staging/auditoria-integral-2026-05-18/teensy-03-linea-fsm.md) |
| **teensy-04** | FSM de **rescate** (claw / depósito) | R-FSM-01 … R-FSM-10 (#57 ramas -90, `ball_counter`/`veces_deposit` init, #123/B6, #125/B8, #120/B4, #112, #60) | [teensy-04-rescate-fsm.md](../../../project/backlog/staging/auditoria-integral-2026-05-18/teensy-04-rescate-fsm.md) |
| **teensy-05** | Serial (lado C++ del protocolo) | 2.1 … 2.9 (handshake 0xFA a medias #72, `green_state` sticky re-dispara rescate, frames stale, desync #63/#70) | [teensy-05-serial-teensy.md](../../../project/backlog/staging/auditoria-integral-2026-05-18/teensy-05-serial-teensy.md) |

> Los timeouts de #61/#62 también vivieron completos en git (commit `cead75e`, después revertido). Los reportes teensy-02/03/04 cruzan con `programa-laureano` — usá ambos.

---

## 2. Lucio Saucedo (`@luciouriel2011`) — Visión RPi 4B (Python / OpenCV / TFLite)

**Fuente primaria de código (snippets Python COMPLETOS + test scripts):**
👉 **[`programa-lucio-rpi-vision.md`](../../../project/backlog/staging/programa-lucio-rpi-vision.md)**

Propone arreglos de robustez para el pipeline de visión: guard headless, init defensivo contra crash, threading seguro en la cámara y manejo de errores en el hilo de inferencia. Todos son cambios chicos (< 20 líneas cada uno), se escriben sin el robot; el banco hace falta sólo para la validación final.

| Issue | Qué propone | Archivo fuente |
|---|---|---|
| **#64** | Guard `HEADLESS` en `calibration.py` (los `cv2.imshow` crashean en la Pi sin pantalla) | [programa-lucio](../../../project/backlog/staging/programa-lucio-rpi-vision.md) |
| **#110** | Inicializar `cx_black = width // 2` para evitar crash 100% reproducible en zona verde sin línea negra | [programa-lucio](../../../project/backlog/staging/programa-lucio-rpi-vision.md) · draft: [draft-issue-resi-cx-black-crash](../../../project/backlog/staging/draft-issue-resi-cx-black-crash.md) |
| **#65 + #113** *(unificados)* | `threading.Lock` + None-check en `camthreader.py` — reescritura completa de `WebcamVideoStream` (evita frame desgarrado/stale y crash al desconectar cámara) | [programa-lucio](../../../project/backlog/staging/programa-lucio-rpi-vision.md) · draft: [draft-issue-resi-camthreader-lock](../../../project/backlog/staging/draft-issue-resi-camthreader-lock.md) |
| **#111** | `try/except` en `infer_thread()` para evitar el **deadlock silencioso** de la cola de rescate si la inferencia tira una excepción | [programa-lucio](../../../project/backlog/staging/programa-lucio-rpi-vision.md) · draft: [draft-issue-resi-infer-thread](../../../project/backlog/staging/draft-issue-resi-infer-thread.md) |

> **Nota Lucio:** #110 es el de mejor ratio impacto/riesgo (una línea, crash determinista). #65 y #113 se resuelven con el **mismo** `Lock` → un solo PR.

### Reportes de auditoría que respaldan estos fixes

| Reporte | Subsistema RPi | Findings | Link |
|---|---|---|---|
| **rpi-01** | Percepción / visión (la mayor densidad de Python del lote) | V18-01 … V18-12 (parse tensor TFLite #124/B7, `silver_mask` en BGR #B2, máscara roja sin wrap #B9, verde LAB #86, `camthreader` sin Lock #113) | [rpi-01-vision.md](../../../project/backlog/staging/auditoria-integral-2026-05-18/rpi-01-vision.md) |
| **rpi-02** | FSM de decisión de alto nivel | D1 … D12 (decisión de verde con ROIs mezclados `cx_black` vs `greenCentroidX`; referencia #110, #120/B2/B3, #127, #123) | [rpi-02-decision.md](../../../project/backlog/staging/auditoria-integral-2026-05-18/rpi-02-decision.md) |

> **Matiz importante sobre "clases YOLO invertidas" (#B3):** **NO** es cierto que las clases del modelo estén invertidas — **coinciden con `metadata.yaml`**. Lo que estaba cruzado eran los **nombres de sub-estados de depósito**, no las clases del modelo. El reporte **rpi-01 (finding V18-03)** ya tiene este matiz y es la fuente de verdad. No repitas "las clases YOLO están invertidas" sin esa aclaración.

---

## 3. Benjamin Villagran (`@benjaminvillagran`) — RPi 4B + Hardware + systemd

**Fuente primaria de código (mixta: systemd + Python + bash + protocolo de banco):**
👉 **[`programa-benjamin-rpi-hardware.md`](../../../project/backlog/staging/programa-benjamin-rpi-hardware.md)**

Rol dual: fixes propios de sistema/comms **+** el **gate de banco** (valida en hardware real los PRs de Lucio y Laureano). Propone auto-restart del proceso, pinneo de dependencias, TX serial defensivo y un protocolo de banco reusable con templates de TEST_LOG.

### 3.1 systemd / arranque

| Issue | Qué propone | Archivo fuente |
|---|---|---|
| **#108** | Unit `robot.service` con `Restart=always` + `RestartSec=2` (auto-restart del proceso `Main.py` si crashea) | [programa-benjamin](../../../project/backlog/staging/programa-benjamin-rpi-hardware.md) · draft: [draft-issue-resi-systemd-rpi](../../../project/backlog/staging/draft-issue-resi-systemd-rpi.md) |

### 3.2 Python (Main.py)

| Issue | Qué propone | Archivo fuente |
|---|---|---|
| **#108** | `__main__` guard + `try/except` de último recurso + handlers de señal con `_emergency_stop()` (manda `speed=0` al Teensy antes de morir) | [programa-benjamin](../../../project/backlog/staging/programa-benjamin-rpi-hardware.md) |
| **#66** | `send_frame_safe()`: clamp de rango (speed/angle) + captura de `SerialException`/`SerialTimeoutException` + contador de errores | [programa-benjamin](../../../project/backlog/staging/programa-benjamin-rpi-hardware.md) |

### 3.3 Config

| Issue | Qué propone | Archivo fuente |
|---|---|---|
| **#68** | `requirements.txt` **pineado** (`==`) desde un `pip freeze` de la Pi de producción, para reproducir el entorno desde una SD limpia | [programa-benjamin](../../../project/backlog/staging/programa-benjamin-rpi-hardware.md) |

### 3.4 Protocolo de banco (gate de calidad reusable)

No es un fix de código: es el **procedimiento de validación en banco** que Benjamin usa para aprobar PRs de RPi/comms (de Lucio y de Laureano). Incluye equipamiento mínimo, flujo de sesión, **tests de inyección de fallas F1–F5** (desconexión de cámara, desconexión UART, `kill -9`, arranque sin cámara, arranque sin Teensy) y templates de entrada para `testing/TEST_LOG.md`.
👉 Sección "Protocolo de banco" en [programa-benjamin](../../../project/backlog/staging/programa-benjamin-rpi-hardware.md).

> **Nota Benjamin:** **ajustá las rutas de la unit systemd y los parámetros a la Pi real** antes de commitear (el `ExecStart`/`WorkingDirectory` dependen de dónde esté el clone). Ningún PR de visión/comms se mergea sin tu check en hardware.

### Reporte de auditoría relacionado

| Reporte | Subsistema | Findings | Link |
|---|---|---|---|
| **rpi-03** | Comms + threading (lado RPi) | CT-01 … CT-11 (#113, #111, #66, #73, #53 lado RPi, #108) + agrupamiento sugerido (FIX-CAM, FIX-PIPELINE-RESCATE, FIX-SERIAL-TX) | [rpi-03-comms-threading.md](../../../project/backlog/staging/auditoria-integral-2026-05-18/rpi-03-comms-threading.md) |

> rpi-03 cruza con `programa-lucio` (#113/#111) y con `programa-benjamin` (#66/#108).

---

## 4. Comms / protocolo serial (ambos lados) — referencia transversal

Estos reportes documentan el **protocolo serial completo** Teensy ↔ RPi. No son de una sola persona: tocan firmware (Laureano) y RPi (Lucio/Benjamin). Sirven como "cabecera" que une los lados C++ (teensy-05) y Python (rpi-03).

| Reporte | Contenido | Estado | Link |
|---|---|---|---|
| **comms-01** | Protocolo integral: tabla de frame `[255,speed,254,angle,253,green,252,silver]`, diagramas de secuencia, presupuesto de bytes/buffer 64 B + fixes **F-1 … F-6** (handshake 0xFA, heartbeat #53, overflow #63/#70, contrato de rangos) | Referencia del protocolo (más diagramas/prosa que código ejecutable) | [comms-01-protocolo-integral.md](../../../project/backlog/staging/auditoria-integral-2026-05-18/comms-01-protocolo-integral.md) |
| **comms-02** | ESP32 / SuperTeam Challenge: estado del módulo. **El ESP32 no existe** (0 código, 0 footprint); hay 2 planes incompatibles (#84 BT-RPi con stub `superteam.py` inexistente vs ESP32–Teensy por Serial8). Único excerpt: los `#define BUZZER 31 / LED_ROJO 30` ya aplicados | **Entrada de ESTADO, no de snippet aplicable** — no hay código propuesto concreto todavía, sólo decisión de arquitectura pendiente | [comms-02-esp32.md](../../../project/backlog/staging/auditoria-integral-2026-05-18/comms-02-esp32.md) |

---

## 5. Coordinación / validación (Enzo, coach) — cómo se validan estas propuestas

👉 **[`programa-enzo-coordinacion-validacion.md`](../../../project/backlog/staging/programa-enzo-coordinacion-validacion.md)**

**No contiene snippets de código del robot.** Es el documento de coordinación/aprobación de Enzo: checklists de validación de PRs (firmware / Python RPi / systemd), criterios de gate por fase, y comandos `gh` de lectura. Útil como referencia de **cómo se aprueba** un PR antes de mergear, no como fuente de código.

> Las fechas de régimen que aparecen ahí (tracks/gates 26-may / 11-jun) son **históricas** → ver [`ESTADO-ACTUAL-2026-05-31.md`](../ESTADO-ACTUAL-2026-05-31.md).

---

## Resumen: dónde está cada cosa

| Si buscás… | Andá a… |
|---|---|
| Código C++ Teensy listo para adaptar | `programa-laureano-teensy-resiliencia.md` |
| Código Python RPi (visión) listo para adaptar | `programa-lucio-rpi-vision.md` |
| systemd + Python sistema + protocolo de banco | `programa-benjamin-rpi-hardware.md` |
| Por qué se propone cada fix (excerpts del código actual) | reportes `teensy-0X` / `rpi-0X` / `comms-0X` en `auditoria-integral-2026-05-18/` |
| Borradores de issue (intención + test plan) | `draft-issue-resi-*.md` |
| Cómo se valida/aprueba un PR | `programa-enzo-coordinacion-validacion.md` |
| Estado real del proyecto y régimen vigente HOY | [`docs/es/ESTADO-ACTUAL-2026-05-31.md`](../ESTADO-ACTUAL-2026-05-31.md) · [informe director](../2026-05-31-informe-coach-auditoria-integral.md) |

---

*Índice generado para que el equipo encuentre y valide las propuestas de código. Recordá: **código propuesto, no commiteado — cada alumno hace su propio PR, prueba en banco y registra en `testing/TEST_LOG.md`.***

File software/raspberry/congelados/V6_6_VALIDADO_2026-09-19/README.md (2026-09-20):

# Base Raspberry validada en pista

Estos son los nueve archivos que el usuario identifico como funcionando en la prueba del 19 de septiembre de 2026. Se conservan byte por byte, incluidos sus saltos de linea, desde:

`C:\Users\villa\Downloads\V6_6_BASE_COMPLETO_CODO_GAP_2026-09-15\V6_6_BASE_COMPLETO_CODO_GAP_2026-09-15\RASPBERRY_V6_6_FIELD_REV`

No modificar esta copia de referencia. Los experimentos posteriores deben hacerse en otra copia. `SHA256SUMS` permite verificar la integridad de cada archivo; `.gitattributes` evita que Git convierta los saltos de linea.

Es una referencia de los nueve archivos seleccionados, no una distribucion completa: requiere el resto de dependencias, modelos y configuracion del paquete original. Guardarla no instala ni cambia el programa que esta ejecutando la Raspberry.

La logica coincide con `software/raspberry/paquetes/V6_6_BASE_COMPLETO_CODO_GAP_2026-09-15/RASPBERRY_V6_6_FIELD_REV` en el commit `1a4878f`; la copia de trabajo de ese paquete tiene diferentes saltos de linea.

Esta base aun tiene `ROI_ARRIBA=60` por defecto y no interpreta los avisos de rampa `0xF2/0xF3/0xF4`. El ajuste anterior de ROI de subida se hizo en otra variante, `EN_EL_ROBOT/main.py`, y no esta incorporado aqui. La subida sigue pendiente de una prueba y un cambio acotado sobre una copia de esta base.

El usuario confirmo en pista el rele HIGH durante rescate y el giro doble verde de 180 grados. Durante esta captura, el archivo local de Teensy contenia otros ajustes en curso (170 grados y verdes +/-45); esta instantanea de Raspberry no los altera.

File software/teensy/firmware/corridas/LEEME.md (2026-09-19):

# Corridas del 2026-08-22 — las primeras que corrieron en el robot

Hasta este día **nada de todo el diagnóstico había corrido en el robot**: 9 entornos que
compilaban y 9 herramientas que parseaban, y nada más. Estas son las primeras mediciones
reales. Se guardan crudas y con su procedencia adentro (la línea `# hz=... commit=...`),
que es lo que permite comparar una corrida de hoy contra una de dentro de dos meses.

| archivo | qué es |
|---|---|
| `2026-08-22_banco_piso_historico.csv` | **la línea de base.** Barrido completo, 24 segmentos, lazo histórico (`fix_lazo=0`), cuatro ruedas sobre la pista |
| `2026-08-22_banco_piso_con_fixes.csv` | el mismo barrido con `FIX_LAZO_MOTOR` y `FIX_CURVA_CONTINUA`. 16 segmentos: el grabador enganchó a mitad de la secuencia |
| `2026-08-22_INVALIDA_ruedas_en_el_aire.csv` | **no usar para concluir.** El barrido arrancó solo al bootear con el switch en ON y el robot no estaba apoyado. Se guarda porque es un buen ejemplo de cómo se ve una corrida en el aire: giroscopio en 0,0 d/s y ruedas a 145-195 rpm (velocidad libre) |
| `2026-08-22_PARCIAL_solo_la_cola.csv` | sólo `rotation` 0,85 y 1,00. Se guarda como ejemplo de corrida incompleta |

## Lo que dijeron

    python tools/analizar_barrido.py corridas/2026-08-22_banco_piso_historico.csv

                              sin fixes   con fixes
    rendimiento rot <= 0,50     0,871       0,874
    rendimiento 0,50 - 0,95     0,906       0,884
    rendimiento rot  = 1,00     0,904       0,902
    ruido del banco             0,046       0,045
    colapso                     ninguno     ninguno

**El rendimiento de giro es PLANO**, o sea que por cada unidad de consigna el robot entrega
el mismo giro en todo el rango, con carga y sobre la pista. Eso mata las dos hipótesis que
venían de junio:

- **PID ciego al signo**: ninguna rueda colapsó en ningún segmento de ninguna corrida. La
  rueda interna sigue su consigna: en `rot=0,85` pide 31 rpm y mide 31; en `rot=1,00` pide
  45 y mide 45.
- **Techo de par**: el giro escala con `rotation` y con la velocidad. De 25 a 70 rpm el
  rendimiento cambia 0 %.

Y los dos fixes son **neutros**: no mejoran la actuación —no había nada que mejorar— pero
tampoco la degradan, así que `competencia_fix` no rompe nada.

El piso anti-coast se ve funcionando: en `rot=0,40` el PWM mínimo pasa de 0 (histórico) a
20 (con fix), que es exactamente `MOTO_PWM_ANTICOAST`, sin distorsionar el giro.

## Dónde quedó el problema

Si la actuación es fiel, el problema está **aguas arriba de los motores**: en qué `rotation`
se le pide. Lo que sigue es una corrida de pista con la cámara, mirando las columnas
`rxsteer` (el ángulo que mandó la Raspberry) contra `rot` (lo que decidió el drivebase).

## Cómo NO medir

Tres formas de arruinar una corrida, las tres pasadas hoy:

1. **Con las ruedas en el aire.** Se detecta solo: el giroscopio da ~0 y las ruedas van a
   velocidad libre. El analizador se niega a dar veredicto.
2. **Enganchando la cola de un barrido anterior.** El archivo parece completo pero le
   faltan las rotations bajas. El grabador ahora exige empezar por una `rotation` baja.
3. **Midiendo un binario que no es el que se creía haber subido.** `pio run --target upload`
   reporta **SUCCESS aunque el Teensy no haya entrado en modo programación**. Hay que
   apretar el pulsador de la placa y después verificar contra la línea de procedencia que
   emite la propia Teensy, no contra el mensaje del cargador.

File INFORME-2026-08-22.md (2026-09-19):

# Informe consolidado — sábado 22-ago-2026

> **Histórico.** Leer primero [CURRENT_TRUTH_2026-08-23.md](CURRENT_TRUTH_2026-08-23.md).

_Equipo IITA Salta, Roboliga 2026 (Rescate). Reemplaza a `TRASPASO-2026-08-22.md`._

**El robot está disponible una vez por semana, 3 h 30.** Este informe existe para que el
análisis se haga **sin el robot en la mano**, con los datos que se grabaron ese día.

> **Actualizado el 2026-08-23:** el analisis sin robot corrigio varias conclusiones de
> este informe (los videos son de 33,3 fps y no 20; `rxsteer` esta x1000; la autoridad de
> giro nunca se duplico; el hallazgo de las 22:01 no es atribuible). Leer
> **[ANALISIS-2026-08-23.md](ANALISIS-2026-08-23.md)** ANTES que esto.

---

## El problema, sin adornos

El robot **no toma las curvas cerradas** desde que se pasó de "2 fijas + 2 omni" a
**4 ruedas fijas de silicona**. En rectas anda.

Al cerrar el día del 22-ago: **se sigue saliendo.** Se probaron 8 configuraciones de
control. Ninguna lo resolvió. Lo que sí hay ahora, que antes no había, son **datos**.

---

## Los datos que quedaron (esto es lo que hay que analizar)

### 10 videos de pista — `software/raspberry/final_rpi/*.avi`

Formato: **640×240 a 20 fps**. Panel izquierdo = el frame de **160×120 que el robot
realmente procesó**, escalado ×2 sin interpolar → se recupera EXACTO con `f[:, :320][::2, ::2]`.
Panel derecho = la máscara. (`con_planner.avi` es de 320×240, sin panel de máscara.)

| hora | archivo | frames | qué corría |
|---|---|---|---|
| 20:29 | `con_planner.avi` | — | planner manejando, 1er intento |
| 20:32 | `con_planner2.avi` | — | planner manejando, con panel de máscara |
| 21:02 | `roi_auto.avi` | — | `atan2` de siempre + ROI adaptativo |
| 21:12 | `lineal.avi` | — | control lineal `K_CERCA=40` |
| 21:18 | `lineal70.avi` | — | control lineal `K_CERCA=70` |
| 21:31 | `a.avi` | — | `ROI=auto RECUP=1` |
| **22:01** | **`como_esta.avi`** | **1498** | **visión ORIGINAL, sin ninguna variable** |
| 22:32 | `hist.avi` | 2091 | rampa cóncava + pivote + histéresis |
| 22:39 | `seguir.avi` | — | lo anterior + `CTRL=lineal K=70` |
| 22:46 | `rumbo.avi` | 1068 | lo anterior + término de rumbo |

### 10 CSV de la Teensy — `software/teensy/firmware/corridas/*.csv`

**45 columnas a 200 Hz.** La primera línea es la nota (qué se probaba). **La cabecera
puede faltar o venir cortada** porque el drenaje del buffer empieza a mitad de línea:
la fuente de verdad es `DIAG_CABECERA` en `src/main.cpp:798`.

```
us,dt,drop,rxsteer,rxspeed,rxage,rxf,rot,ls,rs,ddir,ram,
fl_dir,fl_set,fl_rpm,fl_pwm,fl_enc,fl_tog,fl_raw,
fr_dir,fr_set,fr_rpm,fr_pwm,fr_enc,fr_tog,fr_raw,
bl_dir,bl_set,bl_rpm,bl_pwm,bl_enc,bl_tog,bl_raw,
br_dir,br_set,br_rpm,br_pwm,br_enc,br_tog,br_raw,
yaw,pit,gx,gy,gz
```

**Lo importante: `rxsteer` y `rxspeed` son lo que mandó la Raspberry.** O sea que cada CSV
tiene, en la misma línea de tiempo, **la decisión de la visión Y la respuesta de las cuatro
ruedas**. Eso permite separar sin el robot:

- ¿la orden estaba mal? → mirar `rxsteer`
- ¿la orden estaba bien y las ruedas no la siguieron? → comparar `*_set` contra `*_rpm`
- ¿el robot giró de verdad? → integrar `gz` (o mirar `yaw`)

| archivo | qué probaba |
|---|---|
| `..._banco_piso_historico.csv` | barrido de actuación, 4 ruedas al piso, SIN fixes |
| `..._banco_piso_con_fixes.csv` | el mismo barrido, CON los dos fixes |
| `..._INVALIDA_ruedas_en_el_aire.csv` | **inválido**: ruedas en el aire, no se usa |
| `..._PARCIAL_solo_la_cola.csv` | drenaje parcial, sirve sólo la cola |
| `..._pista_arbol_de_ramas.csv` | curva cerrada, firmware histórico |
| `..._pista_rampa_continua_pivote20.csv` | misma curva, `FIX_CURVA_CONTINUA` |
| `..._pista_gain18.csv` | misma curva, `LINE_STEER_GAIN=1.80` |
| `..._pista_pivote35.csv` | pivote 35 / curva dura 32, gain 1.35 |
| `..._pista_pivote_sin_histeresis.csv` | `LINE_PIVOTE_DESDE=0.60`, rampa cóncava 0.5 |
| `..._pista_pivote_con_histeresis.csv` | histéresis 0.60 / 0.15 |

---

## Las 8 configuraciones medidas

`analizar_corrida.py` mide cualquier video con las mismas 4 métricas y lo compara contra
la base con 5 % de tolerancia.

| corrida | cruces/s | centrado | desvío | perdida | vs base |
|---|---|---|---|---|---|
| **`como_esta` (visión original)** | 1,92 | **51 %** | **14,0** | **12,5 %** | **mejor 3, peor 0** |
| `atan2` original (base) | 1,88 | 42 % | 20,0 | 17,9 % | — |
| `hist` | 2,08 | 35 % | 18,3 | 15,5 % | mezclado |
| `roi_auto` + `RECUP` (`a.avi`) | 1,81 | 35 % | 21,1 | 26,6 % | peor |
| `lineal70` | 1,62 | 37 % | 21,1 | 22,6 % | peor |
| `seguir` (`CTRL=lineal K=70`) | 1,75 | 37 % | 21,9 | 23,9 % | peor |
| `rumbo` (posición + rumbo) | 1,14 | 26 % | 25,7 | 23,1 % | peor 3 |
| planner | 1,07 | 37 % | 19,4 | 24,8 % | peor |
| `lineal` `K=40` | 1,14 | 22 % | 26,1 | 33,9 % | peor |

**Ocho leyes de control y ninguna de las mías le gana al original.** La única que gana es
la que NO toca la visión.

---

## EL HALLAZGO DE LAS 22:01 — y por qué todavía NO es una conclusión

`como_esta.avi` se grabó para mandárselo a un compañero, **sin ninguna variable puesta**:
visión original, `atan2` de siempre, ROI fijo en 60, sin recuperación, sin planner.
Es la mejor corrida del día por lejos.

Cruzando la hora del video con los commits del firmware, a las 22:01 estaba flasheado:

- `FIX_LAZO_MOTOR` + `FIX_CURVA_CONTINUA`, `MOTO_PWM_ANTICOAST = 20`
- `LINE_STEER_GAIN = 1.35`
- **rampa de velocidad cuadrática con `LINE_PIVOT_SPEED = 50`**
- rotation **LINEAL** (la cóncava `pow(absSteer, 0.5)` entró recién 22:12)
- **sin umbral de pivote y sin histéresis** (entraron 22:12 y 22:27)
- `VERDE_RECHEQUEO = 0`, BNO acotado, fix de ToF

Y después, en orden cronológico:

| hora | qué se agregó | centrado | desvío | perdida |
|---|---|---|---|---|
| 22:01 | — (mejor estado) | **51 %** | **14,0** | **12,5 %** |
| 22:32 | rampa cóncava + pivote + histéresis | 35 % | 18,3 | 15,5 % |
| 22:39 | + `CTRL=lineal` | 37 % | 21,9 | 23,9 % |
| 22:46 | + término de rumbo | 26 % | 25,7 | 23,1 % |

**Degradación monótona: todo lo que se agregó después de las 22:01 lo empeoró.**

### El reparo, que hay que resolver antes de dar esto por bueno

Cada corrida es **una vuelta distinta de la pista**, no el mismo tramo. Las métricas
pueden diferir por el tramo recorrido y no por la configuración. Antes de revertir el
firmware a las 22:01 hay que descartar que `como_esta.avi`:

1. no haya recorrido **menos curvas** que las otras;
2. no tenga más proporción de recta (donde todas las configuraciones andan bien);
3. no esté medido sobre una cantidad de curvas cerradas comparable.

**Esa verificación es la primera tarea del análisis.** Si sobrevive, la acción del próximo
sábado es *revertir*, no agregar. Si no sobrevive, el hallazgo se cae y hay que volver a
la tabla.

---

## Lo que quedó CERRADO con datos (no volver a discutir)

### Las dos hipótesis de junio están muertas

Barrido de banco, 24 segmentos, cuatro ruedas sobre la pista:

- **PID ciego al signo** → ninguna rueda colapsó en ningún segmento. La rueda interna sigue
  su consigna: en `rot = 0,85` pide 31 rpm y mide 31; en `rot = 1,00` pide 45 y mide 45.
- **Techo de par** → el rendimiento de giro es **plano** (0,87 – 0,90) en todo el rango,
  con carga y sobre la pista. De 25 a 70 rpm cambia 0 %.

### Frenar para doblar no sirve

La distancia recorrida por grado girado vale `(1 − rot) / (k · rot)`. **La velocidad se
cancela** — verificado con dos corridas de pista a 29 y 37 rpm (0,49 vs 0,44 cm/grado).

| `rot` | cm para girar 90° |
|---|---|
| 0,30 | **44 cm** |
| 0,87 | 3,6 cm |
| 1,00 | **0 cm** |

Lo único que reduce esa distancia es **subir `rot`**.

### Tres cuelgues de arranque

| | estado |
|---|---|
| **ToF**: `setTimeout()` escrito después de `init()`; la guarda `(io_timeout > 0 && …)` da false → seis bucles sin salida | **cerrado** |
| **BNO055**: `while (read8(CHIP_ID) != BNO055_ID) delay(10);` sin salida, dentro de la librería de Adafruit | **cerrado** (`lib/Adafruit_BNO055_acotado/`) |
| **`pio run --target upload` reporta SUCCESS aunque el Teensy no entre en modo programación** | **documentado**, hay verificador |

Los dos primeros dejaban al robot mudo y sin LED, en la pista, delante del árbitro.

### El verde no giraba

```cpp
runTime(20, FORWARD, 0, 800);          // avanza 800 ms
serialEvent5();                        // relee el serial
if (green_state == 1) runAngle(...);   // el verde ya salió del cuadro -> nunca gira
```

`VERDE_RECHEQUEO = 0`. El comportamiento viejo queda a una línea.

### La ganancia del `atan2` está invertida

Medido sobre 3221 frames: **1,45 °/px** a menos de 10 px del centro, **−0,10 °/px** entre
30 y 80 px. Sobrecorrige cuando está casi bien y se queda sin autoridad cuando de verdad
se fue. **Los cuatro reemplazos que probé anduvieron peor igual.**

### El agujero de rotation, cerrado

`rot` no podía tomar ningún valor entre 0,30 y 0,80; el 64 % del tiempo en movimiento caía
en las ramas de pivote duro. `FIX_CURVA_CONTINUA` lo cerró (banda 0,4–0,7: 0 % → 32 %).
Autoridad de giro casi duplicada: **25,9 → 45,2 → 54,0 grados/s**.

---

## LO QUE NO HAY QUE VOLVER A PROBAR (con el número que lo descarta)

- **Bajar la velocidad para doblar mejor.** La velocidad se cancela en cm/grado. Verificado
  con dos corridas a distinta velocidad.
- **`LINE_STEER_GAIN = 1.80`.** Satura antes, usa menos el rango continuo (banda media
  32 % → 22 %) y el cabeceo empeora de −11,8° a −20,3°.
- **`CTRL=lineal` con `K_CERCA=40`.** Centrado 22 %, línea perdida 33,9 %.
- **`LINE_PIVOTE_DESDE = 0.30`.** El `absSteer` está en la banda media el 32 % del tiempo:
  pivotearía casi toda la corrida sin avanzar.
- **El planner (`seguidor_linea.py`) tal como está.** Cuesta 11 ms/frame (55 → 34 fps) y
  sobre una mancha ancha recorre el **borde**, no un centro.
- **El término de rumbo con `K_CERCA=70 / K_LEJOS=60`.** Bajó el rumbo torcido de 28,6 a
  22,3 px pero el centrado se derrumbó de 40 % a 26 %. El balance de ganancias quedó sin
  resolver, pero *ese* par de valores está descartado.

---

## LOS SEIS ERRORES DE MEDICIÓN — el capítulo más útil de todo esto

Cada uno estuvo a punto de producir una decisión equivocada. Todos son míos.

| se afirmó | por qué era falso |
|---|---|
| "la imagen está quemada" | 0 % de frames con píxeles al tope. Es piso claro |
| "el 100 % de los frames sin línea tienen línea arriba del recorte" | era el **salón** (pared, zócalo, patas de mesa). Se contó negro y se lo llamó línea |
| "el 55 % de los frames se comportan como mancha" | la métrica clasificaba 3 de 5 al revés. **Se eliminó la métrica** en vez de publicarla |
| "el robot ve 2,8 cm de piso" | medido en la fila más cercana, donde la perspectiva magnifica más |
| "`setup()` está colgado" (×3) | el registrador **no drenaba con el switch apagado**. La placa estaba perfecta. **Esto costó tiempo de pista** |
| "`CTRL=lineal` corrige rumbo" | tenía los **dos términos como POSICIÓN**. Era un solo término disfrazado de dos. Por eso nunca ganó |

**El patrón es el mismo en los seis: medir sin validar contra un caso donde ya se sabe la
respuesta.** Los sintéticos pasaban con las métricas rotas, porque `medir()` rota la imagen
180° y el sintético quedaba dado vuelta.

**Regla que sale de acá: toda métrica nueva se valida primero contra 3 casos reales de
respuesta conocida. Si clasifica uno al revés, se tira la métrica.**

---

## LO QUE ESTÁ FLASHEADO AHORA (entorno `diagnostico_fix`)

Esto es lo que quedó en la placa al cerrar el día — **no es el mejor estado medido**.

```
fix_lazo=1  fix_curva=1  anticoast=20.0  sin_imu=0  lazo=nuevo
```

| constante | valor | nota |
|---|---|---|
| `MOTO_PWM_ANTICOAST` | 20 | era 45, tapaba al lazo en toda curva |
| `LINE_STEER_GAIN` | 1.35 | 1.80 empeoró el cabeceo |
| `LINE_ROT_EXP` | 0.50 | rampa cóncava. **Entró 22:12, después del mejor estado** |
| `LINE_PIVOTE_ENTRA` / `SALE` | 0.60 / 0.15 | histéresis. **Entró 22:27** |
| `LINE_PIVOTE_MAX_MS` | 2500 | tope de seguridad |
| `LINE_PIVOT_SPEED` | 50, rampa `k²` | estaba en el mejor estado |
| `VERDE_RECHEQUEO` | 0 | el verde gira |
| `PLATEADO_TEENSY` | 0 | decisión explícita de Benjamín |
| `LINEA_PERDIDA_GS` | 4 | `case 4`: retrocede 200 ms y vuelve a mirar |

**Compilado pero NUNCA flasheado:** la confirmación de alineación sostenida de 300 ms para
la salida del pivote. Ataca el hecho medido de que **el 81 % de las salidas de pivote
vuelven a entrar en menos de 400 ms** porque `absSteer` cae de 0,70 a 0,12 después de sólo
11° de giro real (una curva pide ~90°).

---

## LO ÚLTIMO QUE SE MIDIÓ: posición vs rumbo

Observación de Benjamín en pista, confirmada con números: el robot **queda chueco** después
de una curva y sigue así hasta que pierde la línea en la siguiente.

| corrida | centrado | de esos, con RUMBO torcido | rumbo mediano estando centrado |
|---|---|---|---|
| `hist.avi` | 40 % | **57 %** | 28,6 px |
| `seguir.avi` | 43 % | 61 % | 27,9 px |
| `rumbo.avi` | 26 % | 53 % | 22,3 px |

**Está centrado el 40 % del tiempo, pero más de la mitad de esos frames tiene el rumbo
torcido.** Los 8 controladores probados son de POSICIÓN solamente. El término de rumbo bajó
el error de rumbo pero rompió el centrado: el balance de ganancias quedó sin resolver.

---

## LAS HERRAMIENTAS

**Teensy** — `software/teensy/firmware/`

| entorno | qué es |
|---|---|
| `teensy_hid_device` | competencia (`default_envs`) |
| `diagnostico_fix` | **el flasheado**: robot + CSV 200 Hz + los dos fixes |
| `banco_barrido` / `_fix` | barrido de actuación, sin pista ni visión |
| `banco_pines` / `banco_girar` / `banco_i2c` | diagnóstico de encoders, motores y bus |

`tools/analizar_barrido.py` — el veredicto usa **rendimiento de giro** `giro/(2·|rot|·vel)`,
con umbral derivado de la dispersión entre las 4 repeticiones (2σ, piso 5 %).

**Raspberry** — `software/raspberry/final_rpi/`

| archivo | qué es |
|---|---|
| `parche_planner.py` | parchea el `main.py` de la Pi. Backup, reversible, todo apagado por defecto |
| `analizar_corrida.py` | **la vara común**: mide cualquier video contra la base |
| `medir_camara.py` | cobertura del ROI (única métrica de cámara que resultó estable) |
| `seguidor_linea.py` | el planner (leer antes "lo que no hay que volver a probar") |

Interruptores del parche: `ROI=auto`, `CTRL=lineal`, `RECUP=1`, `RETROCEDER=1`,
`PLANNER=1|2`, `GRABAR=ruta`, `K_CERCA`, `K_LEJOS`, `RECUP_ANG`, `SATURA_DESDE`, `AREA_MIN`.

---

## REGLAS DE LA CASA

- **Verificar contra el código, no contra la documentación.** Si se contradicen, gana el código.
- **Compilar no es funcionar, y flashear tampoco**: `pio` miente. Verificar contra la línea
  de procedencia que emite la propia Teensy.
- **Una variable por corrida.** Ese día se perdieron dos corridas midiendo dos cambios juntos.
- **Toda conclusión se pone a refutar antes de darla.**
- **Español rioplatense.** El jurado entrevista a los alumnos.

---

## LAS PREGUNTAS ABIERTAS — esto es lo que tiene que contestar el análisis

Todas se pueden contestar **sin el robot**, con los videos y los CSV que ya están grabados.

**P1 — ¿La ventaja de `como_esta.avi` es real o es confound de tramo?**
Comparar cuántas curvas cerradas recorrió cada corrida. Si recorrió menos curvas, el
hallazgo se cae.

**P2 — ¿Qué pasa exactamente en los 2 segundos previos a cada pérdida?**
Extraer todos los episodios de pérdida sostenida de los 10 videos y caracterizarlos:
¿la línea estaba en el borde? ¿el ángulo estaba saturado? ¿venía de curva o de recta?
**Ésta es la pregunta directa de "por qué todavía pierde la línea".**

**P3 — ¿La orden estaba mal, o las ruedas no la siguieron?**
En los CSV de pista: durante las curvas, comparar `rxsteer` (lo que pidió la visión) con
`*_set` vs `*_rpm` (lo que hicieron las ruedas) y con `gz` integrado (lo que giró de
verdad). Separa definitivamente visión de actuación.

**P4 — ¿Cuándo satura el ángulo en 90?**
Benjamín observó que `angle = 90` es la firma de que se salió. Cuantificar en qué fracción
del tiempo y en qué contexto ocurre.

**P5 — ¿La rampa cóncava y el pivote empeoraron las cosas?**
Es lo que sugiere la degradación monótona post-22:01. Verificar contra los CSV
`pivote_sin_histeresis` y `pivote_con_histeresis`.

**P6 — ¿Hay algo en el código actual que contradiga lo que este informe afirma?**
Regla de la casa: gana el código.

---

## ESTADO AL CERRAR

**Las dos hipótesis de junio, muertas con datos. La causa geométrica identificada y
cuantificada. Tres cuelgues de arranque encontrados, dos cerrados. El verde arreglado.
Autoridad de giro duplicada.**

**Y el robot todavía se sale en la curva cerrada.**

La pista más prometedora no es una idea nueva: es que **el mejor estado medido del día se
alcanzó a las 22:01 y todo lo que se agregó después lo empeoró.** Si eso sobrevive a la
verificación de P1, la acción del próximo sábado es **revertir, no agregar.**

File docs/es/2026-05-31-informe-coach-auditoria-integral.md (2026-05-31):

# INFORME EJECUTIVO PARA EL COACH

## Auditoría Integral del Proyecto — RCJ Rescue Line 2026 · IITA Salta

**De:** Gustavo Viollaz (Director) **· Para:** Enzo Juarez (Coach) **· Fecha:** 31-05-2026
**Mundial:** RoboCup Junior Rescue Line — Incheon, Corea — 30-jun a 06-jul-2026 (**~30 días**)
**Base:** auditoría de 26 agentes sobre el repo (24 análisis de subsistema + 3 informes por integrante), datos verificados a mano contra `origin/main` (`1841dcb`) el 31-05-2026.

---

### MENSAJE DEL DIRECTOR

> **Enzo: están perdiendo el foco.** Se está trabajando en cosas intrascendentes —agregar finales de carrera, sumar un módulo de comunicación ESP32, intentar hacer videos— **sin CONCRETAR lo importante**. Falta **TRABAJO PROFESIONAL**. Falta **DOCUMENTACIÓN**. Falta **CARGAR TODO EN EL REPOSITORIO**: lo que no está en `main` no existe. Tenemos talento y tenemos buen diagnóstico, pero el trabajo no se cierra, no se mergea y no se documenta. **Estamos a tiempo —pero tienen que CAMBIAR LA FORMA DE TRABAJO AHORA.** Esta semana, no la que viene.

---

### RESUMEN EJECUTIVO

**Diagnóstico en una línea:** el equipo identificó el blanco correcto y le apuntó bien, **pero la bala está atascada en la recámara (PR #129) y la maneja un solo tirador (Benjamin).** El riesgo #1 a Incheon **no es técnico: es de proceso —merge, bus-factor y documentación.**

**Semáforo por frente:**

| Frente | Estado |
|---|---|
| Análisis y diagnóstico de bugs | 🟢 Nivel mundial — saben qué está mal |
| Visión (features: TFLite, NCNN, anti-destello, 91 FPS medidos) | 🟢 Lo más maduro |
| **Cierre / merge a `main`** | 🔴 Todo el código real represado en PR #129 sin mergear |
| Firmware (control/rescate) | 🔴 PID saturado, velocidad mal en curva, rescate por FSM muerta |
| Comms / resiliencia / auto-recuperación 8-10 | 🔴 Sin heartbeat, sin handshake real, sin WDT → hoy es aspiracional |
| **TDP / Poster / Video** | 🔴 No existen: ~6-12/102 · 0/18 · 0/24 |
| Balance de personas | 🔴 Bus-factor = 1 (Benjamin escribió el 100% del código del último mes) |
| Hardware (diseño) | 🟢 Arquitectura correcta, alineada con campeones |
| Uso de IA (visión + herramienta de desarrollo) | 🟢 Maduro, transparente, premiable |

**Los 5 riesgos P0:**

1. **PR #129 no se mergea** → el robot que viaja tiene los bugs B1-B10 vivos. *Verificado: `drivebase.cpp:50` en `main` sigue con el PID saturado; `priority_fix_flags.h` no existe en `main`.*
2. **Bus-factor = 1.** Benjamin = 100% del código del último mes. Laureano no toca código desde el 14-mar; Lucio tiene 0 líneas vivas en visión siendo el dueño. No podrán debuggear en el pit.
3. **Documentación de jurado en cero** (~72 pts de presentación + reliability sin respaldo). El TEST_LOG en `main` está vacío.
4. **Comms sin red de seguridad** (sin heartbeat #53, el Teensy nunca emite el handshake 0xFA, sin WDT) → un cuelgue deja el robot inerte.
5. **El rescate corre por código fantasma:** la FSM no-bloqueante está 100% muerta; corre la vieja secuencia inline bloqueante. **El equipo tunea código que no se ejecuta.**

**Conclusión:** el talento y el criterio están a nivel mundial (lo prueban los issues #57-#128). Lo que falta no es saber qué hacer — es **cerrar: mergear, repartir y documentar en la rama que cuenta.** A 30 días, con las 3 palancas del anexo movidas esta semana, "podio + aprender" sigue siendo alcanzable.

<!-- PAGEBREAK -->

### INFORME GENERAL DEL PROYECTO

**Programas — Teensy (firmware).** Es el subsistema que más puntos gana o pierde en pista y el menos atendido las últimas semanas.
- **PID (B1/#121) — reinterpretado:** los motores son DFRobot FIT0441 con **PWM invertido** → el `255 - _pwmVal` es *correcto* a nivel HW. El problema real es el lazo (PID en modo DIRECT + `ki=22` dominante + `kp=0`) que **nunca regula y queda saturado a fondo**. *El fix naïve que se había propuesto EMPEORA el robot:* es rediseño de lazo, no un cambio de signo (`teensy-01-drivebase-pid.md`).
- **Navegación (B5/#122):** la velocidad sube a 55 en curva con lógica invertida → causa #1 de salidas de pista. `taskDone` nunca vuelve a `false` (solo anda tras un OFF→ON manual). Esquiva de obstáculo con `random()` sin semilla. La línea roja de fin de pista (`green_state==10`) se ignora: el robot no frena al terminar.
- **Rescate (P0 central):** existen **dos FSM de pinza contradictorias**; la no-bloqueante (`actualizarRescate()`, `claw.cpp`) está **100% muerta** y corre la vieja inline bloqueante (`main.cpp:1137-1186`). `ball_counter`/`veces_deposit` con init contradictorio → salida anticipada del cuarto (#123/B6). La salida final NO está implementada → el robot queda contra la pared.
- **Sensores:** el revert `cead75e` borró los timeouts (#59-#62) → sin timeout en `colorDataReady`, `while(1)` infinito ante fallo de init de BNO055/APDS9960.

**Programas — RPi (visión + decisión).** El más maduro, pero con un P0 binario sin confirmar:
- **#124/B7 (P0, 48h):** el parseo del tensor TFLite asume `[N,6]` con NMS embebido, pero `metadata.yaml` dice `end2end:false`. Si no trae NMS, el `infer_thread` (sin try/except, #111) **crashea → el rescate no funciona en absoluto.** **Hay que medir `out.shape` esta semana.**
- **#B2:** `silver_mask` en BGR con umbrales HSV → el único trigger de entrada a rescate está mal. **#B9:** rojo `H∈[1,7]` sin wrap. Causa raíz transversal: exposición/balance de blancos de la cámara sin fijar.
- La FSM 'depositar' ciega el YOLO a todas las víctimas → robot clavado en la zona verde.

**Comms + ESP32.** El protocolo quedó **desincronizado entre placas** por el revert: la RPi ya tiene el protocolo nuevo (0xFA, clamp, timeout) pero el Teensy **nunca emite 0xFA** → el fail-safe es ilusorio. El buffer de Serial5 es de **64 bytes** y desborda en ~0,27 s bajo maniobras. **El ESP32 NO está incorporado** (ni HW ni SW): solo es propuesta. Peor: el firmware **ya remapeó pines** (BUZZER 35→31, LED 34→30) para una ESP32 que nunca se montó → estado inconsistente. Hay **dos planes de SuperTeam incompatibles** (ESP32-Teensy vs BT-RPi) sin decidir.

**Hardware.** Arquitectura **acertada y alineada con campeones**, pero: (a) las **3 representaciones del hardware no coinciden** entre sí ni con el robot real (firmware con BNO055 ↔ esquemático con ESP32 ↔ PCB.json con MPU6050 → no se puede re-fabricar el board desde el repo); (b) `hardware/bom/` vacío, sin CAD/STL 2026; (c) **P0 de potencia:** la RPi se alimenta de un buck **sub-dimensionado** (reinicios que matan el 8-10 de auto-recuperación) y **no hay fusible** ni protección de LiPo.

**Documentación (puntaje HOY → potencial):** **TDP** ~6-12/102 → 71-89 (no existe como archivo; el draft de Lucio está en Google Drive fuera del repo). **Poster** 0/18 → 13-18 (bloqueado por acceso al Canva, #45). **Video** 0/24 → 20-22 (**los 5 clips crudos son POV de la cámara onboard, inservibles — hay que filmar de nuevo**, #94). El TEST_LOG en `main` está vacío.

**Novedad defendible:** la arquitectura NO es novedosa (es el "patrón campeón"). Lo defendible: el **pipeline anti-destello adaptativo** (implementado) y la **validación multimodal de víctima** (diseñada, no embarcada). **Riesgo: vender diseño como implementación** — el claim de "auto-recuperación 8-10" es hoy el más peligroso porque nada está mergeado.

**Estrategia — los 2 desvíos:** (1) el TDP se metió dentro del PR #129 y **bloquea la entrada de los fixes que sí corren en pista**; (2) **scope creep impropio a 30 días** (finales de carrera, ESP32/SuperTeam, Technical Challenges, refactors) — todo eso distrae con un solo programador. **Hay que recortar y cerrar.**

<!-- PAGEBREAK -->

### INTEGRANTE 1 — Laureano Monteros (@Laumonteros) · Firmware Teensy (owner)

**Actividad (datos duros, `git log`/`gh`):** 6 commits de contenido, **todos en marzo (07-14)**, **0 en abril-mayo** (~2,5 meses sin tocar `main` a 30 días del mundial). +534/−90 líneas. 2 PRs (#37, #39), ambos mergeados por el coach con **0 reviews formales**. **0 issues autorados.** **14 issues asignados OPEN** (sus #25/#27 originales + los 6 de CORRECTITUD). **0 entradas en TEST_LOG.** Commitea bajo 2 identidades git (unificar `user.email`).

**Calidad — lo bueno (mérito genuino, leído en `claw.cpp`/`claw.h`):** la **FSM no-bloqueante de la pinza** es el patrón correcto y ataca directo su propio issue #25; `begin()` separado del constructor con comentario sobre orden de init de globales → sofisticado para su nivel. **Mejor instinto de arquitectura de firmware del equipo.**

**Calidad — lo que falla:** su mejor commit (`ec8e6ab` "Timeout/Watchdogs") **NO es ancestro de `main`** (`git merge-base` lo confirma) → **su mejor trabajo está perdido.** Su FSM de pinza está **muerta** (corre la inline bloqueante). El bug B5/#122 vive en `main.cpp:1066` **porque es justo el código que él intentó borrar** → no es reincidencia, es trabajo no integrado. PR #37 marinó 7 semanas y declara `Closes #123` (que no existía) → **aceptó salida de IA sin verificar** (lo declaró honestamente, eso está bien). `variables_doc.md` ya quedó desactualizado.

**Fortalezas:** arquitectura de firmware · ataca los problemas correctos (resiliencia) · iniciativa de documentar · transparente con el uso de IA · dueño real de subsistema.

**Debilidades:** desconexión temporal (riesgo #1) · cero verificación en banco · acepta IA sin auditar · no hace follow-up de sus PRs hasta verlos en `main` · higiene de proceso floja.

**Recomendaciones para Enzo:** (1) **Reactivarlo con una victoria garantizada: #115 = recuperar SUS timeouts** (`git show ec8e6ab` existe) — máximo ROI técnico + psicológico. (2) Pedirle **una** entrada de TEST_LOG de la pinza (y descubrir juntos que su FSM no corre). (3) Triage guiado de sus 6 issues B*. (4) Enseñarle a **verificar la IA** (¿el issue del `Closes` existe? ¿la variable significa lo que creo? ¿lo probé en banco?). (5) Emparejarlo con Benjamin + check-ins semanales de 15 min para forzar continuidad.

**Veredicto:** *talento de arquitectura por encima del promedio del equipo, lastrado por disciplina e involucramiento muy por debajo de lo que exige un mundial.* Si se reconecta, es el firmware-lead que el equipo necesita.

<!-- PAGEBREAK -->

### INTEGRANTE 2 — Lucio Saucedo (@luciouriel2011) · RPi Visión (owner)

**Actividad (datos duros):** 5 commits no-merge (el menor de los 3 alumnos). 2 PRs: #36 (fix C++ punteros) **mergeado**; #42 (comentarios) **OPEN desde marzo, abandonado** tras feedback del coach del 29-abr. **0 issues autorados, 0 reviews. Última actividad 2026-04-25 → +1 mes de silencio** entrando a la recta final.

**Calidad — el hallazgo que define todo:** por `git blame` sobre la versión viva, **Lucio tiene 0 líneas en TODO el código de visión** (`Main.py`, `camthreader.py`, `calibration.py`, `AI/`) pese a ser el dueño. Sus dos aportes con sustancia cayeron **fuera de dominio**: el fix de firmware (`strcmp` por comparación de punteros, PR #36 — técnicamente impecable, agregó hasta el guard `!= NULL`) y un **TDP de 411 líneas** de buena calidad. Pero el TDP está **varado sin mergear** en la rama `documentation_and_diagrams`, en inglés sin review, con un error de hecho ("RPi 5" en vez de 4B). **Agravante de gobernanza (#46):** dice tener un draft "desarrollado en su mayoría" en **Google Drive** que el coach pidió **dos veces** (1-abr y 29-abr) sin respuesta.

**Lectura clave:** **el problema NO es de talento** —el fix de punteros y el TDP lo prueban— **es de aplicación fuera de dominio, falta de continuidad y entregables sin cerrar.**

**Fortalezas:** sabe programar y razona bugs de verdad · escribe documentación técnica de calidad (el TDP es hoy su mayor aporte potencial al puntaje) · respeta convenciones · trabaja sin romper.

**Debilidades:** desalineación rol↔realidad (bus-factor de visión = 1) · desconexión sostenida (+1 mes) · patrón de "no termina lo que empieza" (PR #42 y el TDP varados) · no participa del proceso de equipo (0 reviews) · sin hábito de banco.

**Recomendaciones para Enzo:** (1) **ROI máximo: rescatar el TDP** — pedirle el link del Drive (#46), cherry-pick de `TDP/` + imágenes a `main`, corregir "RPi 5"→"4B". Es el mayor salto de puntaje disponible y le devuelve ownership de algo que SÍ hizo bien. (2) **Bus-factor 2 en visión por pairing dirigido** (NO reasignación): hacerlo **dueño de la calibración de color en sede** (HSV plata + verde LAB, conecta con #B2/#B9) — tarea chica, medible, con commit + TEST_LOG. (3) Cerrar PR #42. (4) **La conversación 1:1** (deuda de equipo, no de código): entender por qué se desconectó y salir con 2-3 tareas con fecha.

**Veredicto:** *por debajo de lo esperado para el rol, pero no por incapacidad.* La materia prima es buena; falta engancharla al rol y al equipo antes de viajar — y las 3 acciones de mayor impacto son recuperables en pocas horas.

<!-- PAGEBREAK -->

### INTEGRANTE 3 — Benjamin Villagran (@benjaminvillagran) · RPi + Hardware + Banco

**Actividad (datos duros):** **28 commits** (todas las ramas), **#2 del repo después del coach**, cadencia sostenida feb→may (último 24-may). **El 100% del código del último mes es suyo.** Ojo: las "41k líneas" son engañosas (~34k son PDF binario del PCB); el aporte real ronda 5-6k líneas. ~30 issues asignados (**desproporcionado**). Mensajes de commit buenos (25/28 Conventional Commits).

**Calidad — fortalezas reales (verificadas, no halago):** `hardware/cambios_de_hardware.md` (717 líneas, 100% suyas) es **el mejor documento del repo** — cita reglamento 2026, evalúa opciones con pros/contras, anticipa modos de falla físicos (fatiga del cable de la garra). **Honestidad técnica:** en `code-reliability-evidence` separa explícitamente "mecanismos en código" de "mediciones físicas" y aclara *"physical testing must still validate…"*. Sus mejoras de comms del lado RPi (clamp #66, timeout serial #73, telemetría #75) **sí están en `main` y funcionan** → cuando el trabajo es acotado, lo lleva a producción.

**Calidad — el talón de Aquiles (PROCESO, no capacidad):** casi todo su trabajo P0/P1 de fiabilidad —y el TEST_LOG que la rúbrica más valora— está **varado en PR #129 (OPEN, +5707/−506, 39 archivos, 0 reviews).** `main.cpp` en `main` tiene 2 menciones de timeout; en #129 tiene 64. **Si hoy se flashea desde `main`, el robot no tiene esos fixes.** El TEST_LOG en `main` está **vacío**; los 2 tests reales (T-001 batería/odometría, T-002 **91.33 FPS** medidos) viven sin mergear y con **n=1**. PR #50 (+1946) se mergeó con 0 reviews. El PR #129 es **materialmente irreviewable** (multi-dominio + TDP duplicado + assets + `image.png` suelto).

**Fortalezas:** documentación de hardware profesional · honestidad técnica · código de fiabilidad competente (`priority_fix_flags.h` con feature-flags por issue) · volumen y amplitud reales (es el motor de contenido del equipo).

**Debilidades:** **su trabajo de fiabilidad no llega a `main`** (P0) · banco vacío en `main`, tests reales sin mergear y con n=1 · PRs sobredimensionados y merge sin review (reincidente) · sobrecarga de ~30 issues que lo estira · binarios/basura en el repo (#69).

**Recomendaciones para Enzo:** (1) **[P0] Partir #129** en PR-A firmware/timeouts → PR-B RPi/systemd → PR-C TEST_LOG → PR-D TDP, y **mergear lo seguro con banco**. (2) **[P0] Completar `MEDICIONES_PENDIENTES.md`** (~1h banco: pickup X/10, deposit 5+5, voltaje de estrés). (3) **Regla dura: nada se mergea sin `APPROVED`; PRs <400 líneas, un dominio.** (4) Validar su capacidad primero, luego enseñarle que *"terminar = mergeado y probado, no escrito"*. (5) Re-balancear su carga de issues (pasar comms #70-#76 a otros) y darle ownership del TDP §Electronics.

**Veredicto:** *talento y esfuerzo altos, mejor documentador del equipo, frenado por disciplina de entrega.* Si parte y mergea #129 y completa el banco, pasa de mayor potencial latente a **mayor impacto real** del equipo.

<!-- PAGEBREAK -->

### ANEXO — PRIORIDADES (qué hacer, en qué orden) · 1/2

**Régimen vigente (corregido al 31-05):** la ventana de push libre de firmware (Track A) **ya venció**; todo entra por review de Enzo. Docs/visión (Track B) push libre hasta 11-jun. **Freeze de código propuesto: 15-jun** (deja 15 días para banco + viaje).

#### LAS 3 COSAS QUE MÁS MUEVEN LA AGUJA (esta semana)

1. **DESBLOQUEAR Y MERGEAR EL CÓDIGO DE #129 (con banco).** Pedir a Benjamin que **parta #129 en dos**: PR-código (drivebase, main.cpp, Main.py, systemd, `priority_fix_flags.h`) → mergear **primero** con sesión de banco; PR-TDP → después. *Mientras #129 esté abierto, el robot que viaja tiene B1-B10 vivos.* **Meta: PR-código en `main` antes del 05-jun, con T-003 de validación.**
2. **ROMPER EL BUS-FACTOR.** Laureano y Lucio escribiendo **CÓDIGO** ya, con pairing. Laureano ejecuta #115 (recuperar SUS timeouts); Lucio toma #124/B7 + #110 y **trae su TDP del Drive al repo.** **Meta: ≥3 commits de código de cada uno mergeados antes del 10-jun.**
3. **AGENDAR LA SESIÓN DE FOTOS Y EXIGIR EL CANVA.** Única acción no delegable del coach, mayor ROI por hora en documentación: un sábado con robot + equipo + cámara desbloquea **Poster (18) + Video (18 de 24) + TDP §Mechanical.** Confirmar la **deadline real de subida del video** (único piso de calendario irreducible).

#### PLAN POR SEMANAS (responsables: B=Benjamin, L=Lucio, La=Laureano, E=Enzo, D=Director)

**Semana 0 — Destrabe (31-may → 07-jun):**
- [E+D] Review y **partir PR #129**; mergear PR-código + T-001/T-002 a `main`.
- [La] #115 → recuperar timeouts #60/#61/#112. [B] #72 → emisor 0xFA del Teensy (15 min). [B/La] #57 (signo rama pared) + init de `ball_counter`/`veces_deposit` + delay pinza plateada.
- [L] **#124/B7 → medir `out.shape` del TFLite** (define si el rescate funciona). Luego #110 + #111. **Traer el TDP del Drive (#46).**
- [E, no delegable] Exigir Canva (#45) + **agendar fotos (#94).** [D/E] Decidir SuperTeam (Ruta B BT-RPi ya, ESP32 como migración).
- [D/E] Etiquetar `post-incheon` el scope creep (#88/#81/#82/#83/#87/#84 + finales de carrera). [B] Git LFS (#69) antes de clonar en Corea.
- **Hito: SIMULACIÓN SuperTeam 1** (ver abajo).

**Semana 1 — Estabilizar y filmar (08-jun → 14-jun):**
- [La] #122/B5 + #125/B8 (validar en banco, T-XXX). [La/B] Activar la FSM de rescate o documentar por qué se queda con la inline + **implementar la salida del cuarto.** [B] #53 heartbeat + #27 WDT. [L] #B2 + #B9. [La] #121/B1 → **sesión de diseño del PID** (NO quick-win).
- [B/L sábado] **Sesión de fotos #94 + filmar tomas externas** del robot. [L+B] Ensamblar el cuerpo del TDP (objetivo ~40 pts). [La+B] #41 diagrama de software.
- **Hito: SIMULACIÓN SuperTeam 2** (ver abajo).

<!-- PAGEBREAK -->

### ANEXO — PRIORIDADES · 2/2

**Semana 2 — Documentar y endurecer (15-jun → 21-jun) · FREEZE DE CÓDIGO el 15:**
- [La/B] #126/B10 calibrar encoder. **[B] Hardware P0: buck ≥5A real para la RPi + fusible/PTC** (los reinicios matan el 8-10). [E] Régimen de banco: 2 sesiones fijas/semana, cada una ≥1 entrada en TEST_LOG.
- [L+B] **TDP cuerpo completo** (objetivo 71-89) con la sección de visión/IA y la declaración de uso de IA. [La/B] Maquetar **Poster** en Canva (13-18). [B] Editar **Video** con tomas nuevas + narración en inglés (20-22). [E/D] Pasar `cambios_de_hardware.md` de "propuesta" a "as-built" honesto.

**Semana 3 — Logística y ensayo (22-jun → 29-jun):**
- [Todos] Ensayos completos cronometrados (línea + rescate + recuperación), midiendo el 8-10 real. Pairing en el pit. [E/D] **Subir TDP, Poster, Video.** [B] Kit de pit (SD clonada #38, repo clonable offline, baterías, repuestos). Viaje a Incheon.

#### REGLAS DE TRABAJO NUEVAS (no negociables, desde hoy)

1. **Lo que no está en `main` no existe.** Nada de Google Drive ni ramas eternas. Cargar TODO al repo.
2. **Ningún merge sin un `APPROVED` formal.** PRs chicos (<400 líneas) y de un solo dominio.
3. **Ningún fix de firmware se mergea sin su entrada en TEST_LOG** (Regla de Oro #3, hoy incumplida por los 3).
4. **Cada alumno escribe CÓDIGO de SU subsistema cada semana** (check-in de 15 min). Se terminó el "aparezco, brillo una semana, desaparezco".
5. **Recortar el scope:** nada de finales de carrera, ESP32 ni Technical Challenges hasta after-Incheon. Foco en robot core + documentación.

#### LAS 2 SIMULACIONES SUPERTEAM (listas para asignar)

El SuperTeam Challenge es **independiente** (premio propio, no afecta el puntaje individual), premia **cooperación entre equipos de distinto idioma**, la tarea se anuncia **recién en Incheon**, canal 2.4 GHz con espectro **no garantizado** (hay que tolerar pérdida). Detalle completo en `superteam-00-dos-ejercicios.md`.

- **SIMULACIÓN 1 — "Lenguaje común sin radio" (~2h30, Semana 0/1):** acordar un protocolo de cooperación en ≤15 min **sin idioma común** (solo íconos) y ejecutar un handoff **sin radio** (percepción + tiempo + señales LED/buzzer). Cero riesgo, no depende de la decisión ESP32/BT. Produce el "protocolo de aplicación" que hoy no existe.
- **SIMULACIÓN 2 — "Handshake y degradación con canal real" (~3h, Semana 1):** primer canal inter-robot funcional (Bluetooth nativo de la RPi, sin abrir el robot) con handshake + barrera + **prueba de degradación** (cortar la radio → los robots NO se cuelgan). Crea `superteam.py`. **Regla dura: el canal SuperTeam NO toca el UART frágil Teensy↔RPi.**

---

*Informe sintetizado de la auditoría integral de 26 agentes (31-05-2026). Reportes de respaldo (24 archivos) en `project/backlog/staging/auditoria-integral-2026-05-18/`. Datos verificados a mano sobre `origin/main` (`1841dcb`): PID saturado vivo en `drivebase.cpp:50`; `priority_fix_flags.h` ausente en `main`; TEST_LOG vacío; PR #129 OPEN (+5707/−506, 39 files, 0 reviews); 73 issues y 8 PRs abiertos. Marco "temas a analizar" (riesgo-no-actuar / riesgo-actuar / tiempo), no "bugs a fixear".*

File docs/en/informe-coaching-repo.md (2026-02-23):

<!-- AUTO-GENERATED FILE – DO NOT EDIT.
     Source: docs/es (Spanish is source of truth)
     This file is generated by GitHub Actions.
-->

# Repository Coaching Report (RCJ Rescue Line) — IITA Salta

**Creation Date:** 2026-02-23 (America/Argentina/Salta)  
**Created by:** AI ChatGPT 5.2 (GPT-5.2 Pro)  
**At the request of:** Gustavo Viollaz  
**Analyzed repository:** `IITA-Proyectos/rcj-2026-rescue-line-iita-salta-robocup` (branch `main`)  
**Repo standard:** ICRS v1.1 L2 (`AI-INSTRUCTIONS.md`)  
**Language:** This document lives in `docs/es/` (Spanish = source). `docs/en/` is auto-generated mirror (**DO NOT EDIT**).

---

## Objective

This report is a technical-professional review of the repository and the project's status, focusing on:

- **Competition**: RoboCupJunior Rescue Line (baseline: rules 2025; note: drafts for 2026 exist).
- **Competitive performance**: robustness, repeatability, timing, and failure control.
- **TDP / Documentation**: evidence and typical artifacts required by templates/rubrics (TDP, BOM, technical video, poster).
- **Best practices**: what strong teams tend to do (engineering + testing + traceability).

> Important: this audit is based on what is visible at the time of the review (2026-02-23). If files were added later (e.g., in `hardware/` or `testing/`), this report must be updated.

---

## Applied Standardization (repo conventions)

According to the README and `AI-INSTRUCTIONS.md`, the documentation is organized as follows:

- `docs/es/`: source documentation in Spanish (truth).
- `docs/en/`: auto-generated mirror in English (**do not edit**).
- Suggested convention for file names: **kebab-case** in lowercase (e.g.: `yolo-raspberry.md`).
- Change process: **every change should originate from an Issue** and enter via PR (see `CONTRIBUTING.md` and `AI-INSTRUCTIONS.md`).

**Recommended name and location for this report:**
- ✅ `docs/es/informe-coaching-repo.md` (this file)

---

## Executive Summary (the most important in 2 minutes)

### Strengths (signals of a “serious” team)
1. **Repository with clear ICRS structure** (software/hardware/docs/testing/journal/research/competition/project).  
2. **Well-defined dual processor architecture**: Teensy (real-time) + Raspberry Pi (vision/AI).  
3. **Useful existing technical documentation** (RPi↔Teensy communications, YOLO on Raspberry, firmware libraries).  
4. **Industry-style contribution rules** (Conventional Commits, PR with evidence, declaration of AI usage).

### Areas for Improvement (what often separates “doing” from “winning”)
1. **Work traceability**: the repo shows 0 Issues → lacks a “playable” backlog (tasks, responsibilities, dates, risks).  
2. **Testing evidence with results**: `testing/` is declared, but there is no clearly accessible index/test table.  
3. **TDP readiness**: for high scores, often missing (or not one click away): electrical diagram/power tree, schematics/PCB, official BOM, CAD with measurements, physical location of sensors, and performance metrics.

### Detected Competitive Technical Risks (high priority)
- String comparison by pointer in `drivebase.cpp` (likely bug).
- Possible mixing of units mm/cm in distance control.
- Logic with `delay()` / blocking loops in firmware: latency and event loss.

---

## Reviewed Evidence (internal links)

Key existing documents:
- `docs/es/comunicacion-rpi-teensy.md`
- `docs/es/yolo-raspberry.md`
- `docs/es/librerias-firmware.md`

Repo policies:
- `README.md` (structure, robot, links to docs)
- `CONTRIBUTING.md` (commits/branches/PRs/AI)
- `AI-INSTRUCTIONS.md` (ICRS and process rules)

Code with relevant signals:
- `software/teensy/firmware/src/main.cpp`
- `software/teensy/firmware/lib/drivebase/drivebase.cpp`
- `software/teensy/firmware/lib/claw/claw.h`

---

## Evaluation by Area

### 1) Process and Management (what the repo “says” vs what “is seen”)

**What the repo says should be done (very well):**
- All work originates from an **Issue**.
- Changes enter via PR with **testing evidence**.
- AI usage is declared.

**What is currently observed:**
- “Issues” tab at 0 → **gap between ideal process and real practice**.

**Concrete recommendation (action):**
- Activate a minimum flow:
  - 1 Issue per feature (e.g.: “Fix ToF units”, “Non-blocking FSM”, “Testing gaps table”).
  - labels: `bug`, `enhancement`, `docs`, `hardware`, `testing`, `competition`.
  - milestones: “Roboliga / Regional / National / World”.

> Winning teams are not differentiated by “ideas”: they are differentiated by having a system that makes ideas reach the track and remain stable.

---

### 2) Documentation and TDP (how ready they are for the grid)

#### 2.1 What is already strong
- **Communications** documented with table and bytes (good for TDP).
- **Vision pipeline** explained (better if metrics are added).
- **Dependencies** and libraries listed (reduces judge questions).

#### 2.2 What is missing (or not visible/1 click away)
For TDP and typical rubrics, it is missing to consolidate in one place:

**Hardware**
- Block diagram of the robot (high level).
- Electrical diagram + “power tree” (battery → regulators → loads).
- Schematics/PCB (PDF + source).
- Physical layout of sensors (photo + drawing + measurements).
- Complete BOM using the **official template**.

**Software**
- State diagram (line/rescue/deposit) in graphic (flowchart).
- Description of algorithms (line, greens, gaps, obstacles, rescue) with “edge cases”.
- Configuration and calibration (what parameters exist and how they are adjusted).

**Testing**
- Test table + results (success %, time, failure modes).
- Videos/internal links by feature.
- Logs (even if CSV) by run to compare improvements.

---

### 3) Teensy Firmware (robustness and control)

#### 3.1 Strengths
- Modular structure (`drivebase`, `claw`, PID, sensors).
- Competitive sensor suite (IMU, ToF, color, ultrasonic, encoders).
- Clear state machine at the intention level.

#### 3.2 Risks / likely bugs (high priority)

**(A) Incorrect string comparison**
In `software/teensy/firmware/lib/drivebase/drivebase.cpp`, a pattern is observed:
- `if (this->id == "FL" || this->id == "BL") ...`

In C/C++, this compares **pointers**, not content. It is a classic bug that may “work” by chance and then break.

✅ Recommendation:
- replace with `strcmp(id, "FL")==0` or, better, use `enum MotorID`.

**(B) Units mm vs cm**
In `src/main.cpp`, readings `readRangeContinuousMillimeters()` (mm) are used, but constants commented in cm.
If units are mixed, control becomes erratic (over-correction or slowness).

✅ Recommendation:
- Define a single unit (mm recommended) and normalize everything in `config.h`.

**(C) Blocking / delays**
`while(routine==...)` loops with `delay()` and long actions make the robot slow to react and may degrade serial communication.

✅ Recommendation:
- Non-blocking FSM by “ticks” using `millis()`/`elapsedMillis`.

---

### 4) Raspberry Pi (vision + AI)

#### 4.1 Strengths
- Use of ONNX Runtime + ultralytics (on CPU) is a valid path if measured.
- Multithreading / separation of capture and inference (according to docs).

#### 4.2 Competitive recommendation (what strong teams do)
Measure and record, as if it were Formula 1 telemetry:
- Real FPS (average and percentiles).
- Inference latency (ms).
- Correct detection rate (by class) in real track.
- Robustness to lighting (cold/warm, shadows, reflections, dirty camera).

Without numbers, AI often feels “magical” until the competition day when it stops being so.

---

## 5) Testing and Evidence

**Current status:**
- The repo structure includes `testing/`, but no `testing/README.md` was found to act as an index.
- In `CONTRIBUTING.md`, evidence in PR is required (very good).

**Minimum recommendation (high return):**
Create `testing/README.md` with a simple table:

| Feature | Setup | Metric | Result | Evidence | Date |
|---|---|---|---|---|---|

And within `testing/`:
- `videos/` (short mp4s by feature)
- `logs/` (CSV)
- `photos/` (setup)

---

## TDP Checklist (to transform the repo into “TDP-ready”)

> This list is intended as a production checklist. It does not discuss theory: it aims at what the judge can quickly evaluate.

### Hardware Section
- [ ] Block diagram of the system (Teensy/RPi/sensors/actuators).
- [ ] Electrical diagram / power tree.
- [ ] Schematic (PDF + source).
- [ ] PCB (if exists) + revisions (`rev-a`, `rev-b`).
- [ ] Photos of the robot (4 views) + dimensions.
- [ ] Sensor locations (photo + drawing + distances).
- [ ] Complete BOM (in official template) + suppliers + costs.

### Software Section
- [ ] Architecture (what runs on Teensy vs RPi).
- [ ] State machine (flowchart).
- [ ] Key algorithms and “edge cases”.
- [ ] Parameters / calibration (how, when, with what criteria).
- [ ] Failure management (timeouts, safe modes).

### Validation Section
- [ ] Test plan (feature vs conditions matrix).
- [ ] Quantitative results (success %, times).
- [ ] Videos by feature.
- [ ] Change log: “change → measured improvement”.

---

## Recommended Work Plan (sprints)

### Sprint 1 — Stability (avoid losing rounds due to bugs)
- Fix strings / units / non-blocking FSM.
- RPi↔Teensy communication watchdog.
- Minimum logging (build + parameters + result).

### Sprint 2 — Track Coverage (rules)
- Gaps, greens, obstacles, ramps/seesaw (as available).
- Test table with metrics.

### Sprint 3 — Repeatable Rescue
- Pickup + deposit with measurable success rate.
- Reduction of false positives in vision.

### Sprint 4 — Final Documentation (TDP)
- Consolidate hardware + software + testing into a TDP that “is easy to read”.

---

## Suggested Next Steps (to comply with repo process)

To upload this document correctly according to the repo rules:
1. Create an Issue: “Add repository coaching report”.
2. Create branch: `docs/informe-coaching-repo`.
3. Commit (Conventional Commits): `docs(docs): add repo coaching report`
4. PR with:
   - change summary (adds document),
   - AI declaration (ChatGPT 5.2),
   - link to the Issue.

---

## External Sources (reference)

- RoboCupJunior Rescue Line 2025 Rules (PDF):  
  https://junior.robocup.org/wp-content/uploads/2025/02/RCJRescueLine2025-final-1.pdf

- RoboCupJunior Rescue League — Documents (TDP Template / Rubrics / BOM):  
  https://rescue.rcj.cloud/documents

- RoboCupJunior Rescue Line (general page):  
  https://junior.robocup.org/rcj-rescue-line/

- (Context) Draft Rules 2026 (may change):  
  https://junior.robocup.org/wp-content/uploads/2026/01/RCJRescueLine2026-draft.pdf

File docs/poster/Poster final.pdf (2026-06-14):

# IITA Rescue-BOT

# TEAM

APDS-9960:
Color detection and
verification system. The
APDS-9960 sensor is used
to | identify | different
colors present on the
competition field and
inside the rescue area.
It provides an additional layer of verification for the camera-based detection system, improving reliability and reducing the possibility of false identifications during autonomous operation.

## Raspberry Pi 4

## The Raspberry Pi 4 is responsible for all high-

level computer vision tasks. Using Python,

## OpenCV, and a custom-trained YOLOv8

## model, it processes images captured by the

onboard | camera | to | detect | victims,

## evacuation zones, special line markers, and

## other relevant objects on the field. To improve robustness, the model was trained with more

## than 6,000 images under different lighting conditions and backgrounds, allowing reliable operation in varying

competition environments.

## Once a target is detected, the Raspberry Pi

## calculates its position relative to the camera frame. During victim collection, the robot

## continuously adjusts its movement until the detected victim is aligned with the center of

## the image, increasing collection accuracy and reducing positioning errors. The

## Raspberry Pi then sends navigation and rescue

## commands to the Teensy 4.1 through serial

communication.

HC-SR04 (x3):
Distance | measurement | and | obstacle
detection. These ultrasonic sensors continuously monitor nearby walls and obstacles, providing environmental awareness that helps the robot

VL53L0X (x2):
High-precision wall distance sensing. These Time-of-Flight sensors measure lateral distances from walls and obstacles,

## Teensy 4.1

## The Teensy 4.1 is responsible for all real-time robot control tasks. Developed in C++ using PlatformIO, the firmware manages line

## following, sensor acquisition, motor

control, and rescue-zone operations.

## The control system continuously processes information from the BNO055 IMU, VL53L0X

time-of-flight sensors, ultrasonic sensors,

## color sensors, wheel encoders, and limit

## switches. This data is used to maintain stable

navigation, detect obstacles and walls, identify ramps, estimate traveled distance,

## and execute precise maneuvers throughout the competition field. Limit Switches(x2):

Precise victim deposition positioning. These mechanical sensors confirm physical contact with the evacuation zone,
ensuring the robot is
correctly aligned before
releasing collected
victims.

Its large field of view enables the robot to perceive more of its surroundings, supporting accurate decision-making and autonomous movement throughout the competition.

HW-803 5V Relay Module:
Auxiliary system power control. This relay module allows the robot to safely switch external devices independently from the main controller. It provides electrical isolation and reliable control of auxiliary systems used during rescue and evacuation tasks, improving
operational safety and power
management.
Additionally, it enables secure power distribution to peripheral devices, preventing interference with the robot's primary control electronics and enhancing overall system reliability.

Yosoo Health Gear 2 Million Pixels 140° Camera Computer vision and autonomous navigation. The wide-angle camera captures real-time visual information used for line tracking, green marker detection, victim identification, and rescue zone navigation.

# Artificial Intelligence Mode

Our sensor system enables the robot to detect walls, obstacles, and ramps throughout the course. The gyroscope, BNO055, provides orientation data for accurate turns and ramp navigation. In addition, rear limit switches detect contact with the rescue zone walls, improving stability during rescue maneuvers.
Over the years, our hardware has continuously evolved through mechanical, electronic, and structural improvements, increasing the robot’s precision, reliability, and overall performance.

Our robot features a fully custom chassis designed by our team, composed of 3D-printed parts and a custom PCB that allows us to organize electronic components efficiently and simplify maintenance. It measures 157 mm long by 177 mm wide by 176 mm high and weighs 1,404 grams.
For locomotion, we use front traction wheels that provide grip on the field and rear omnidirectional wheels that improve maneuverability during turns. The drive motors are equipped with encoders, allowing us to accurately measure the distance traveled and perform more precise movements.

# HARDWARE
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

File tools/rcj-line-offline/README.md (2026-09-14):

# RCJ Rescue Line offline (IITA Salta)

Copia offline del **editor de mapas** y la **tablet del juez** de Rescue Line 2026 del RCJ CMS
(https://intl.rcj.cloud), más un **registro de corridas** para entrenar como si fuera oficial.
Todo corre en el navegador: no necesita servidor ni internet para puntuar.
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

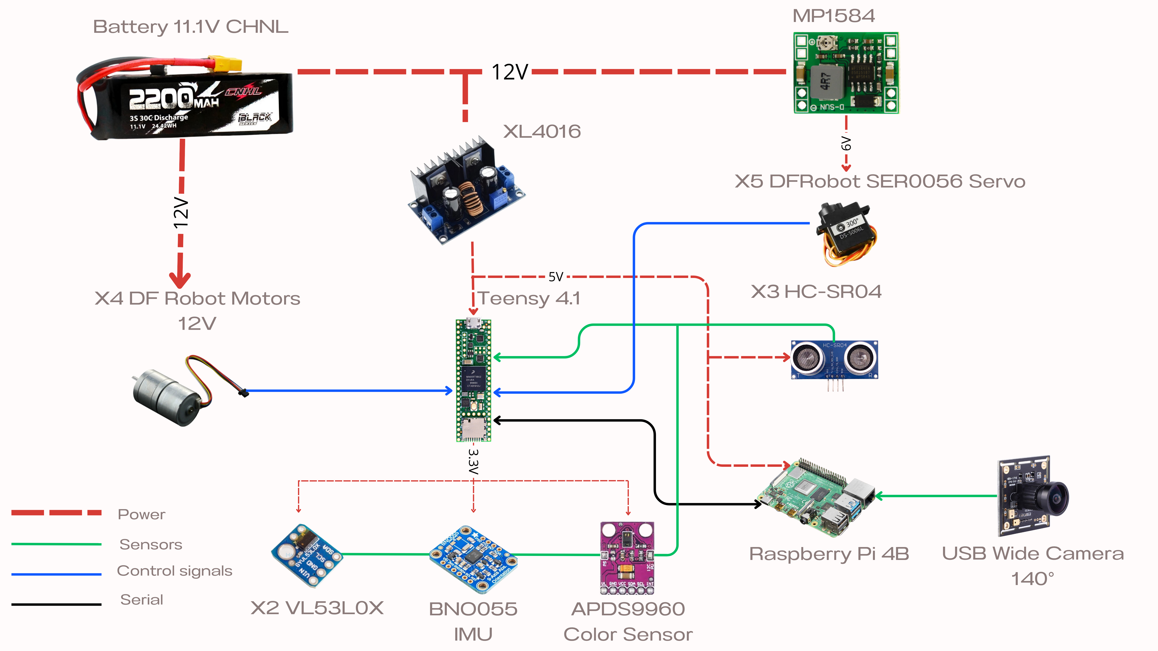
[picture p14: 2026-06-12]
docs/tdp/assets/hardware-overview-2026.png

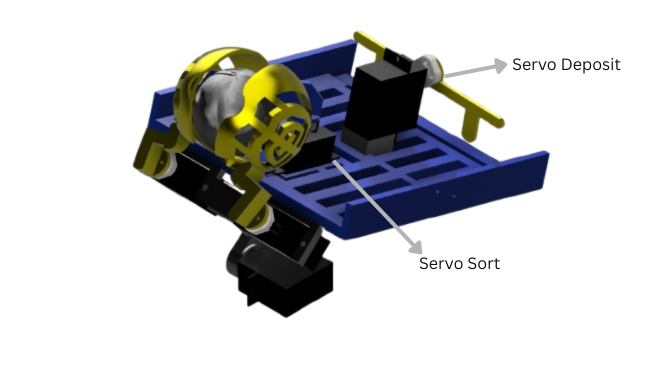
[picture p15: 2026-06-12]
docs/tdp/assets/rescue-mechanism-chassis-2026.png

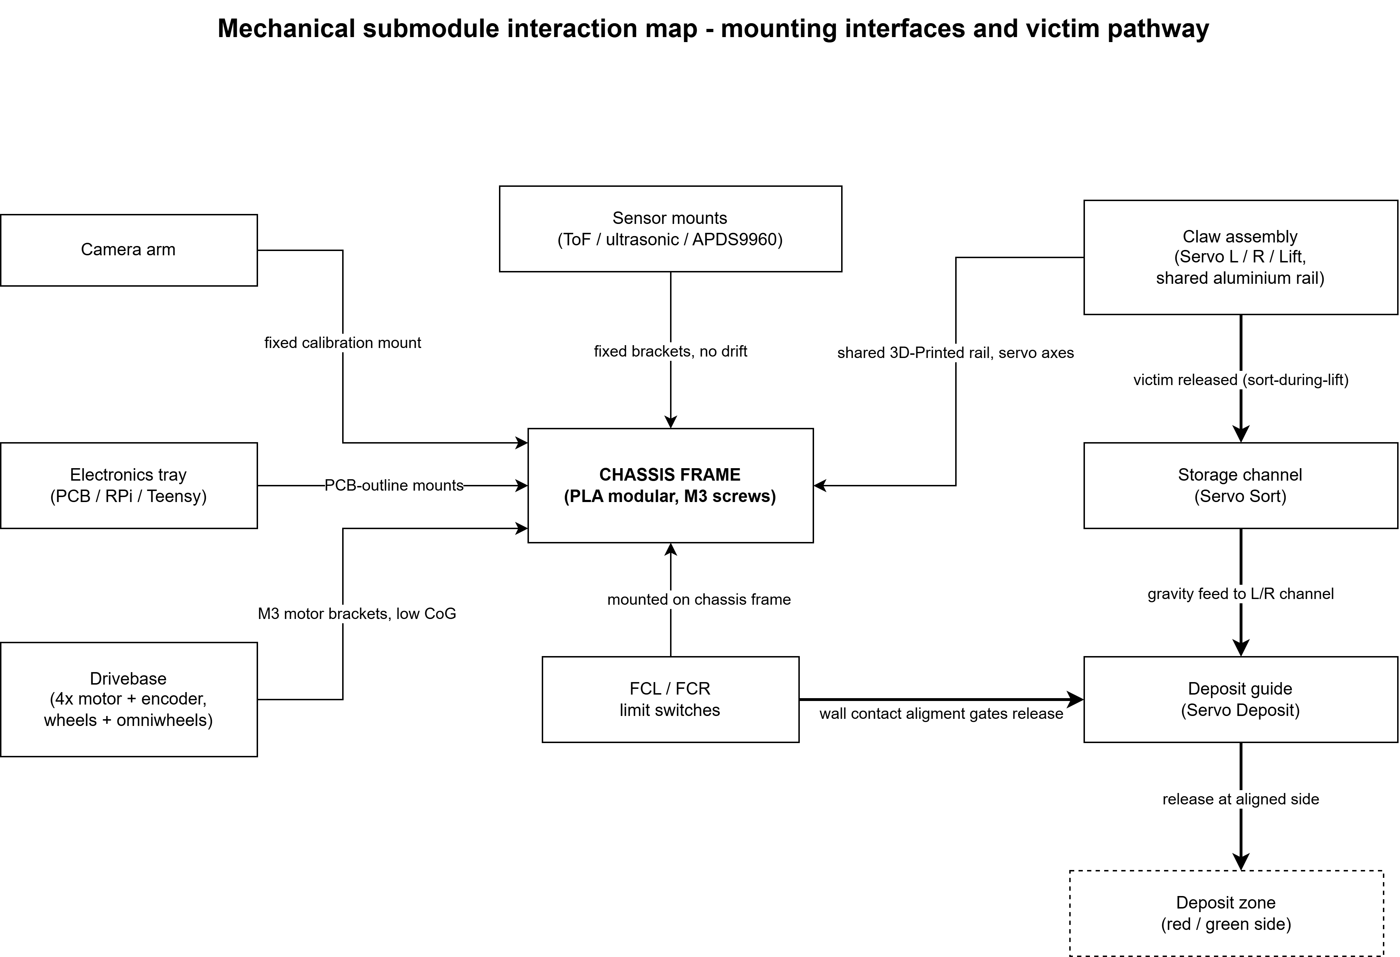
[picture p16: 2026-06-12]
docs/tdp/assets/mechanical-interaction-map-2026.png

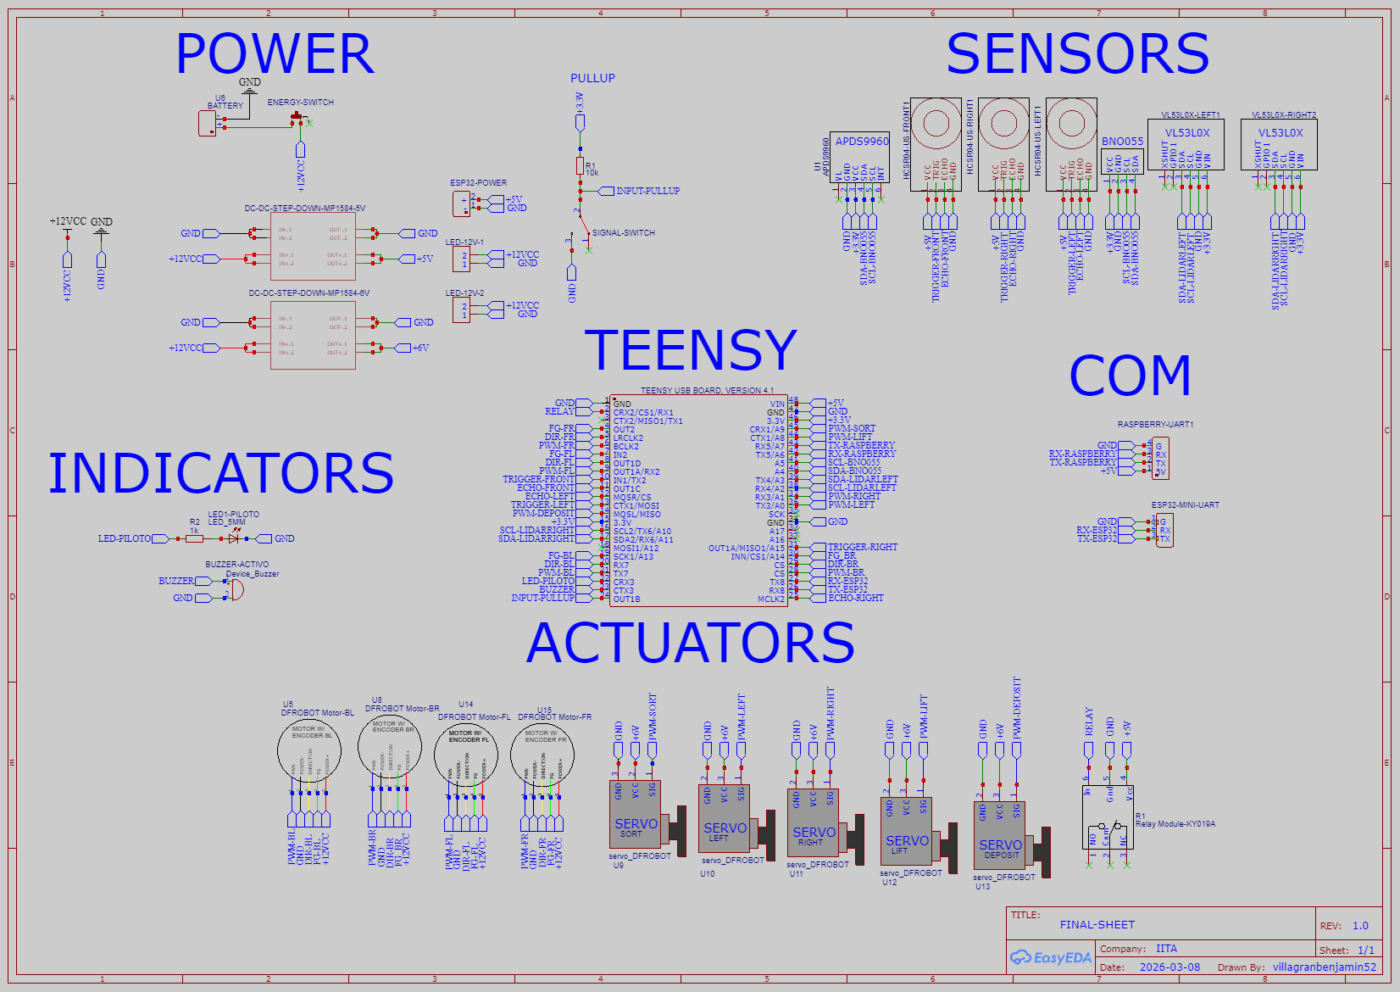
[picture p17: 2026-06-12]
docs/tdp/assets/electronics-schematic-2026.png

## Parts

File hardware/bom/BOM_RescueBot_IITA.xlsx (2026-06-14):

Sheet: Instructions
RESCUE JUNIOR - Bill of Materials (BOM)
Team name: | RescueBot IITA
Every Line/Maze team has to submit a bill of materials for their robot
Instructions:
*Enter Team name above
*All costs need to be in local currency and their approximate conversion into dollars.
*All components worth less can be summarized in one line quantity 1 and their total cost (e.g. Screws)
*In the Local Currency Name column, the team must enter the name of the local currency, if it is different from US dollars.
*In the software sheet, in the Author column, the name of the designer, writer, or company that owns the software or library should be entered. If the team created their own algorithm, dataset, or AI model, they can include their names as authors.
*On the hardware sheet, in the "Author" column, enter the name of the company, engineer, or part manufacturer. If the team made a custom part, such as the robot housing, the team should include their names as the authors.
*IMPORTANT* The "Hardware" sheet is not required for simulation

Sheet: Example HARDWARE
 |  |  |  |  |  |  | Name of the | Total Cost | Total Cost ($)
 | Team name: | RescueBot IITA |  |  |  |  | Local Currency | Local Currency | U.S.A. Dollars
 |  |  |  |  |  |  | Brazilian Real | R$11824.09 | $2094.00
# | Component | Part name | Autor | Source | Quantity | Unit cost (Local Currency) | Unit cost (USA Dollars) | Total Cost (Local Currency) | Total Cost (USA Dollars)
1 | PCB with electronic components | Custom made | Name of team members/Jlcpcb | jlcpcb.com | 1 | R$338.80 | $60.00 | R$338.80 | $60.00
2 | Wheels | Nexus Robot Mecanum Wheel | Nexus Robot | robotshop.com | 4 | R$112.93 | $20.00 | R$451.72 | $80.00
3 | Sheet metall parts for frame | Custom made |  | Local workshop | 1 | R$1129.34 | $200.00 | R$1129.34 | $200.00
4 | Drive motors | Maxon ECX TORQUE 22 XL Ø22 mm | Maxon Group | Maxon Motors | 4 | R$1694.01 | $300.00 | R$6776.04 | $1200.00
5 | Robots shell | Custom made | Name of team members | 3D Printer | 1 | R$112.93 | $20.00 | R$112.93 | $20.00
6 | Robots costume | Custom made | Name of team members | Self made | 1 | R$282.34 | $50.00 | R$282.34 | $50.00
7 | Microcontroller | Arduino Mega 2560 | Arduino | conrad.de | 2 | R$237.16 | $42.00 | R$474.32 | $84.00
8 | Connecting parts | Screws, nuts, washers, ... |  | Local tool store | 1 | R$225.87 | $40.00 | R$225.87 | $40.00
9 | Motors for arm | NEMA-17-01 NEMA-17-01 0.4 Nm 1.68 A | Conrad Electronic | conrad.de | 2 | R$118.58 | $21.00 | R$237.16 | $42.00
10 | Stepper motor controllers | Pololu Tic T825 | Pololu Robotics and Electronics | conrad.de | 2 | R$508.20 | $90.00 | R$1016.40 | $180.00
11 | LEDs | Various colours and sizes | Farnell An Avnet Company | farnell.com | 20 | R$2.82 | $0.50 | R$56.40 | $10.00
12 | Battery | 11.1 V 3700 mAh | Farnell An Avnet Company | farnell.com | 3 | R$203.28 | $36.00 | R$609.84 | $108.00
13 | Cables | Various cables |  | Local electronics store | 1 | R$112.93 | $20.00 | R$112.93 | $20.00
14
15
16
17
18
19
20
21
22
23
24
25
26
27
28
29
30
31
32
33
34
35
36
37
38
39
40
41
42
43
44
45
46
47
48
49
50
51
52
53
54
55
56
57
58
59
60
61
62
63
64
65
66
67
68
69
70
71
72
73
74
75
76
77
78
79
80
81
82
83
84
85
86
87
88
89
90
91
92
93
94
95
96
97
98
99
100

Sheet: Example SOFTWARE
 |  |  |  |  | Name of the | Total Cost | Total Cost ($)
 | Team name: | RescueBot IITA |  |  | Local Currency | Local Currency | U.S.A. Dollars
 |  |  |  |  | Brazilian Real | R$0.00 | $0.00
# | Name | Software's Tool/Library | Description | Source | Autor | Cost (Local Currency) | Cost (USA Dollars)
1 | VL53L0X-Arduino | Library | For controlling the VL53L0X distance sensor on Arduino | pololu/vl53l0x-arduino: Biblioteca Pololu Arduino para VL53L0X sensor de distancia de tiempo de vuelo (https://github.com/pololu/vl53l0x-arduino) | Pololu | FREE | FREE
2 | Open CV | Library | Image processing library | OpenCV - Biblioteca abierta de Computer Vision (https://opencv.org/) | Opencv.org | FREE | FREE
3 | IDE Arduino | Software's Tool | Software | Software | Arduino (https://www.arduino.cc/en/software/) | Arduino.cc | FREE | FREE
4 | Visual Studio Code | Software's Tool | Software | Visual Studio Code: edición de código. Redefinido (https://code.visualstudio.com/) | Microsoft | FREE | FREE
5 | Numpy | Library | Array and math library | NumPy (https://numpy.org/) | Numpy developers | FREE | FREE
6 | Matplotlib | Library | Python graphics generation library | Matplotlib — Visualización con Python (https://matplotlib.org/) | Matplot lib dev team | FREE | FREE
7 | Tinckercad | Software's Tool | Online platform for simulating circuits | Tinkercad (https://www.tinkercad.com/) | Autodesk | FREE | FREE
8 | Git | Software's Tool | Version control for managing functions | Git - Descargas (https://git-scm.com/downloads) | Software Freedom Conservancy | FREE | FREE
9 | Fusion 360 | Software's Tool | 3D CAD shell design | Fusión de Autodesk | Software basado en la nube 3D CAD, CAM, CAE y PCB | Autodesk (https://www.autodesk.com/products/fusion-360/overview) | Autodesk | FREE/EDUCATION | FREE/EDUCATION
10 | Tic Arduino | Library | Library for controlling a Nema 17 stepper motor with the Tic T825 driver | https://github.com/pololu/tic-arduino | DavidEGrayson | FREE | FREE
11 | Modulemotorl298n | Library | The library is designed to make it easy to use motors connected to an L298N module without having to worry about the pins manually in each sketch. |  | Name of team members | FREE | FREE
12
13
14
15
16
17
18
19
20
21
22
23
24
25
26
27
28
29
30
31
32
33
34
35
36
37
38
39
40
41
42
43
44
45
46
47
48
49
50
51
52
53
54
55
56
57
58
59
60
61
62
63
64
65
66
67
68
69
70
71
72
73
74
75
76
77
78
79
80
81
82
83
84
85
86
87
88
89
90
91
92
93
94
95
96
97
98
99
100

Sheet: HARDWARE
 |  |  |  |  |  |  | Name of the | Total Cost | Total Cost ($)
 | Team name: | RescueBot IITA |  |  |  |  | Local Currency | Local Currency | U.S.A. Dollars
 |  |  |  |  |  |  | Argentine Peso | 1031132.16 | $543.29
 |  |  |  |  |  |  | ARS
Exchange rate used: 1 USD = ARS 1,898. Prices reviewed on 2026-06-08. Hardware status and kit/custom-built fields are included in columns L-M.
# | Component | Part name | Autor | Source | Quantity | Unit cost (Local Currency) | Unit cost (US Dollars) | Total Cost (Local Currency) | Total Cost (USA Dollars) | Status | Kit / Custom-built
1 | Main PCB fabrication batch | Team-designed 2-layer PCB, 169.91 mm x 122.91 mm, batch of 5 boards | RescueBot IITA (team) / JLCPCB | JLCPCB Gerber quotation (https://jlcpcb.com/) | 1 | 22889.88 | $12.06 | 22889.88 | $12.06 | New | Custom-built
2 | Chassis & rescue mechanism (custom) | 3D-printed PLA chassis, claw, mounts, storage and deposit guides | RescueBot IITA (team) | Self-made / local PLA estimate | 1 | 35000.00 | 18.44 | 35000.00 | $18.44 | New | Custom-built
3 | Main computer | Raspberry Pi 4 Model B 8GB | Raspberry Pi Ltd | MercadoLibre (https://www.mercadolibre.com.ar/raspberry-pi-4b--8gb-ram-original-made-in-uk/up/MLAU186193431) | 1 | 329005.40 | 173.34 | 329005.40 | $173.34 | New | Commercial part
4 | Microcontroller | Teensy 4.1 | PJRC / SparkFun | SparkFun (https://www.sparkfun.com/teensy-4-1.html) | 1 | 59787.00 | 31.50 | 59787.00 | $31.50 | New | Commercial part
5 | Camera | USB wide-angle camera 140 deg (HBV-1716WA / ASIN B0DR7XXJL1) | Yosoo / HBVCAM | Tiendamia / Amazon mirror (https://tiendamia.com/ar/p/amz/b0dr7xxjl1/2-million-pixels-140-wide-angle-lens-usb-camera-module) | 1 | 47670.00 | 25.12 | 47670.00 | $25.12 | New | Commercial part
6 | IMU | BNO055 9-DOF Absolute Orientation IMU Breakout | Bosch / Adafruit | Adafruit (https://www.adafruit.com/product/2472) | 1 | 66335.10 | 34.95 | 66335.10 | $34.95 | New | Commercial part
7 | ToF distance sensor | VL53L0X module | Generic | MercadoLibre (https://www.mercadolibre.com.ar/modulo-sensor-de-distancia-laser-vl53l0x-arduino-raspberry/up/MLAU3354695184) | 2 | 10989.00 | 5.79 | 21978.00 | $11.58 | New | Commercial part
8 | Ultrasonic sensor | HC-SR04 | Generic | MercadoLibre (https://www.mercadolibre.com.ar/sensor-de-obstaculos-ultrasonico-hc-sr04-arduino/p/MLA2039690988) | 3 | 2940.00 | 1.55 | 8820.00 | $4.65 | New | Commercial part
9 | Color/proximity sensor | APDS-9960 / GY-9960 RGB, gesture and proximity module | Broadcom / Avago / module vendor | MercadoLibre (https://www.mercadolibre.com.ar/sensor-de-colores-gestos-proximidad-rgb-gy-9960-desarrollo/up/MLAU129280454) | 1 | 8090.00 | 4.26 | 8090.00 | $4.26 | New | Commercial part
10 | Drive motor + encoder | DFRobot FIT0441 12V 159RPM brushless motor with encoder | DFRobot | DFRobot (https://www.dfrobot.com/product-1364.html) | 4 | 37770.20 | 19.90 | 151080.80 | $79.60 | New | Commercial part
11 | Servo | DFRobot SER0056 2kg 300 deg clutch servo | DFRobot | DFRobot (https://www.dfrobot.com/product-2126.html) | 5 | 11388.00 | 6.00 | 56940.00 | $30.00 | New | Commercial part
12 | Omniwheel | 58mm aluminum omniwheel, 12kg load rating | Generic / Fulai-style | eBay equivalent (https://www.ebay.com/itm/365966796692) | 2 | 35834.24 | 18.88 | 71668.48 | $37.76 | New | Commercial part
13 | Fixed wheel | Pololu 1420 60x8mm wheel - unit cost split from pair price | Pololu | Pololu (https://www.pololu.com/product/1420) | 2 | 6405.75 | 3.38 | 12811.50 | $6.75 | New | Commercial part
14 | Battery | CNHL LiPo 11.1V 3S 2200mAh 30/60C with XT60 | CNHL | MercadoLibre (https://www.mercadolibre.com.ar/bateria-lipo-cnhl-2200-mah-111v-3s-3060c/up/MLAU3077408699) | 1 | 66119.00 | 34.84 | 66119.00 | $34.84 | New | Commercial part
15 | Buck regulator (compute rail) | XL4016 8A adjustable step-down, set to 5.0V | Generic (XL4016 module) | MercadoLibre equivalent (https://www.mercadolibre.com.ar/fuente-regulador-de-tension-step-down-xl4016-35v-8a-nubbeo/up/MLAU271152181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) | 1 | 8249.00 | 4.35 | 8249.00 | $4.35 | New | Commercial part
16 | Buck regulator (servo rail) | MP1584 3A adjustable step-down, set to 6.1V | Generic (MP1584 module) | MercadoLibre (https://www.mercadolibre.com.ar/modulo-fuente-step-down-08-20v-mp1584-salida-fija-5v-3a/p/MLA2042242028) | 2 | 3799.50 | 2.00 | 7599.00 | $4.00 | New | Commercial part
17 | Power connector | XT60 male/female connector pair | Generic / Amass-style | MercadoLibre (https://listado.mercadolibre.com.ar/fichas-xt60) | 1 | 3545.00 | 1.87 | 3545.00 | $1.87 | New | Commercial part
18 | Limit switches | FCL/FCR micro limit switches for deposit alignment | Generic / Candy-Ho | MercadoLibre (https://www.mercadolibre.com.ar/switch-final-carrera-v-155-1c25-rueda-micro-limit-lever/p/MLA2070049829) | 2 | 4493.00 | 2.37 | 8986.00 | $4.74 | New | Commercial part
19 | Main switch | 12V ON/OFF power/start switch | Generic | MercadoLibre (https://listado.mercadolibre.com.ar/llave-tecla-interruptor-12v) | 1 | 2610.00 | 1.38 | 2610.00 | $1.38 | New | Commercial part
20 | Indicators | Buzzer + status LEDs | Generic | MercadoLibre packs (https://www.mercadolibre.com.ar/led-5mm-alto-brillo-pack-x100-electronica-p-arduino/p/MLA68438197) | 1 | 13449.00 | 7.09 | 13449.00 | $7.09 | New | Commercial part
21 | Relay module | 5V 1-channel relay module | Generic / WEB3ARG | MercadoLibre (https://www.mercadolibre.com.ar/modulo-rele-relay-5v-high-level-10a--1-canal-borne-arduino/up/MLAU3714783990) | 1 | 3499.00 | 1.84 | 3499.00 | $1.84 | New | Commercial part
22 | Wiring & fasteners | Cables, connectors, M3 screws, nuts, standoffs and heat-shrink | Various / local store | Local store estimate | 1 | 25000.00 | 13.17 | 25000.00 | $13.17 | New | Commercial materials / custom assembly

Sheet: SOFTWARE
 |  |  |  |  | Name of the | Total Cost | Total Cost ($)
 | Team name: | RescueBot IITA |  |  | Local Currency | Local Currency | U.S.A. Dollars
 |  |  |  |  | Argentine Peso | R$0.00 | $0.00
Software tools, libraries, team algorithms and AI assets are free/no-cost for the team.
# | Name | Software's Tool/Library | Description | Source | Autor | Cost (Local Currency) | Cost (USA Dollars)
1 | drivebase (custom) | Library | Custom motor/encoder drivebase control for the Teensy | RescueBot IITA repo | RescueBot IITA (team) | FREE | FREE
2 | claw (custom) | Library | Custom five-servo rescue mechanism control: pickup, sort and deposit | RescueBot IITA repo | RescueBot IITA (team) | FREE | FREE
3 | PID (custom/local) | Library | PID control for motor and movement regulation | RescueBot IITA repo | RescueBot IITA (team) | FREE | FREE
4 | Adafruit BNO055 | Library | Driver for the BNO055 9-DOF IMU | github.com/adafruit/Adafruit_BNO055 | Adafruit | FREE | FREE
5 | Adafruit APDS9960 | Library | Driver for the APDS-9960 color/proximity sensor | github.com/adafruit/Adafruit_APDS9960 | Adafruit | FREE | FREE
6 | Adafruit Unified Sensor / BusIO | Library | Sensor abstraction and I2C device layer | github.com/adafruit | Adafruit | FREE | FREE
7 | VL53L0X (Pololu) | Library | Driver for the VL53L0X time-of-flight sensor | github.com/pololu/vl53l0x-arduino | Pololu | FREE | FREE
8 | NewPing | Library | HC-SR04 ultrasonic helper library included locally for tests/examples | bitbucket.org/teckel12/arduino-new-ping | Tim Eckel | FREE | FREE
9 | Servo (Arduino) | Library | Servo PWM control for rescue mechanism | arduino.cc (https://www.arduino.cc/reference/en/libraries/servo/) | Arduino | FREE | FREE
10 | elapsedMillis | Library | Non-blocking timing helper | github.com/pfeerick/elapsedMillis | Paul Stoffregen / community | FREE | FREE
11 | OpenCV contrib Python | Library | Image processing for line, marker and rescue-zone vision | pypi.org/project/opencv-contrib-python | OpenCV.org | FREE | FREE
12 | NumPy | Library | Array and math operations | numpy.org | NumPy developers | FREE | FREE
13 | pySerial | Library | UART communication with the Teensy | pyserial.readthedocs.io | pySerial developers | FREE | FREE
14 | TensorFlow Lite Runtime | Library | On-device victim/zone inference | tensorflow.org/lite | Google | FREE | FREE
15 | Ultralytics YOLOv8 | Library | Rescue-detector training and export | ultralytics.com | Ultralytics | FREE | FREE
16 | AGCWD + anti-flash preprocessing (custom) | Algorithm | Adaptive illumination correction for the 2026 LED-wall rule | RescueBot IITA repo | RescueBot IITA (team) | FREE | FREE
17 | CentroidTracker (custom) | Algorithm | Target stability/tracking between AI inferences | RescueBot IITA repo | RescueBot IITA (team) | FREE | FREE
18 | camthreader (custom) | Library | Threaded camera capture with latest-frame buffer | RescueBot IITA repo | RescueBot IITA (team) | FREE | FREE
19 | Rescue victim/zone dataset + exported model (custom) | Dataset / AI model | Roboflow dataset and YOLOv8/TFLite/ONNX model trained by the team | Roboflow dataset - roboliga-2025-kh2ly (https://app.roboflow.com/enzzorobotics/roboliga-2025-kh2ly) | RescueBot IITA (team) | FREE | FREE
20 | PlatformIO | Software's Tool | Teensy firmware build system | platformio.org | PlatformIO | FREE | FREE
21 | Visual Studio Code | Software's Tool | Code editor | code.visualstudio.com | Microsoft | FREE | FREE
22 | Fusion 360 | Software's Tool | 3D CAD design of chassis and rescue mechanism | autodesk.com (https://www.autodesk.com/products/fusion-360/overview) | Autodesk | FREE/EDUCATION | FREE/EDUCATION
23 | EasyEDA | Software's Tool | PCB schematic and layout design | easyeda.com | EasyEDA / LCSC | FREE | FREE
24 | Roboflow | Software's Tool | Dataset annotation and management | roboflow.com | Roboflow | FREE | FREE
25 | Kaggle | Software's Tool | Model training and validation with cloud notebooks/GPU | kaggle.com | Kaggle / Google | FREE | FREE
26 | Git / GitHub | Software's Tool | Version control and repository hosting | github.com | GitHub / Software Freedom Conservancy | FREE | FREE

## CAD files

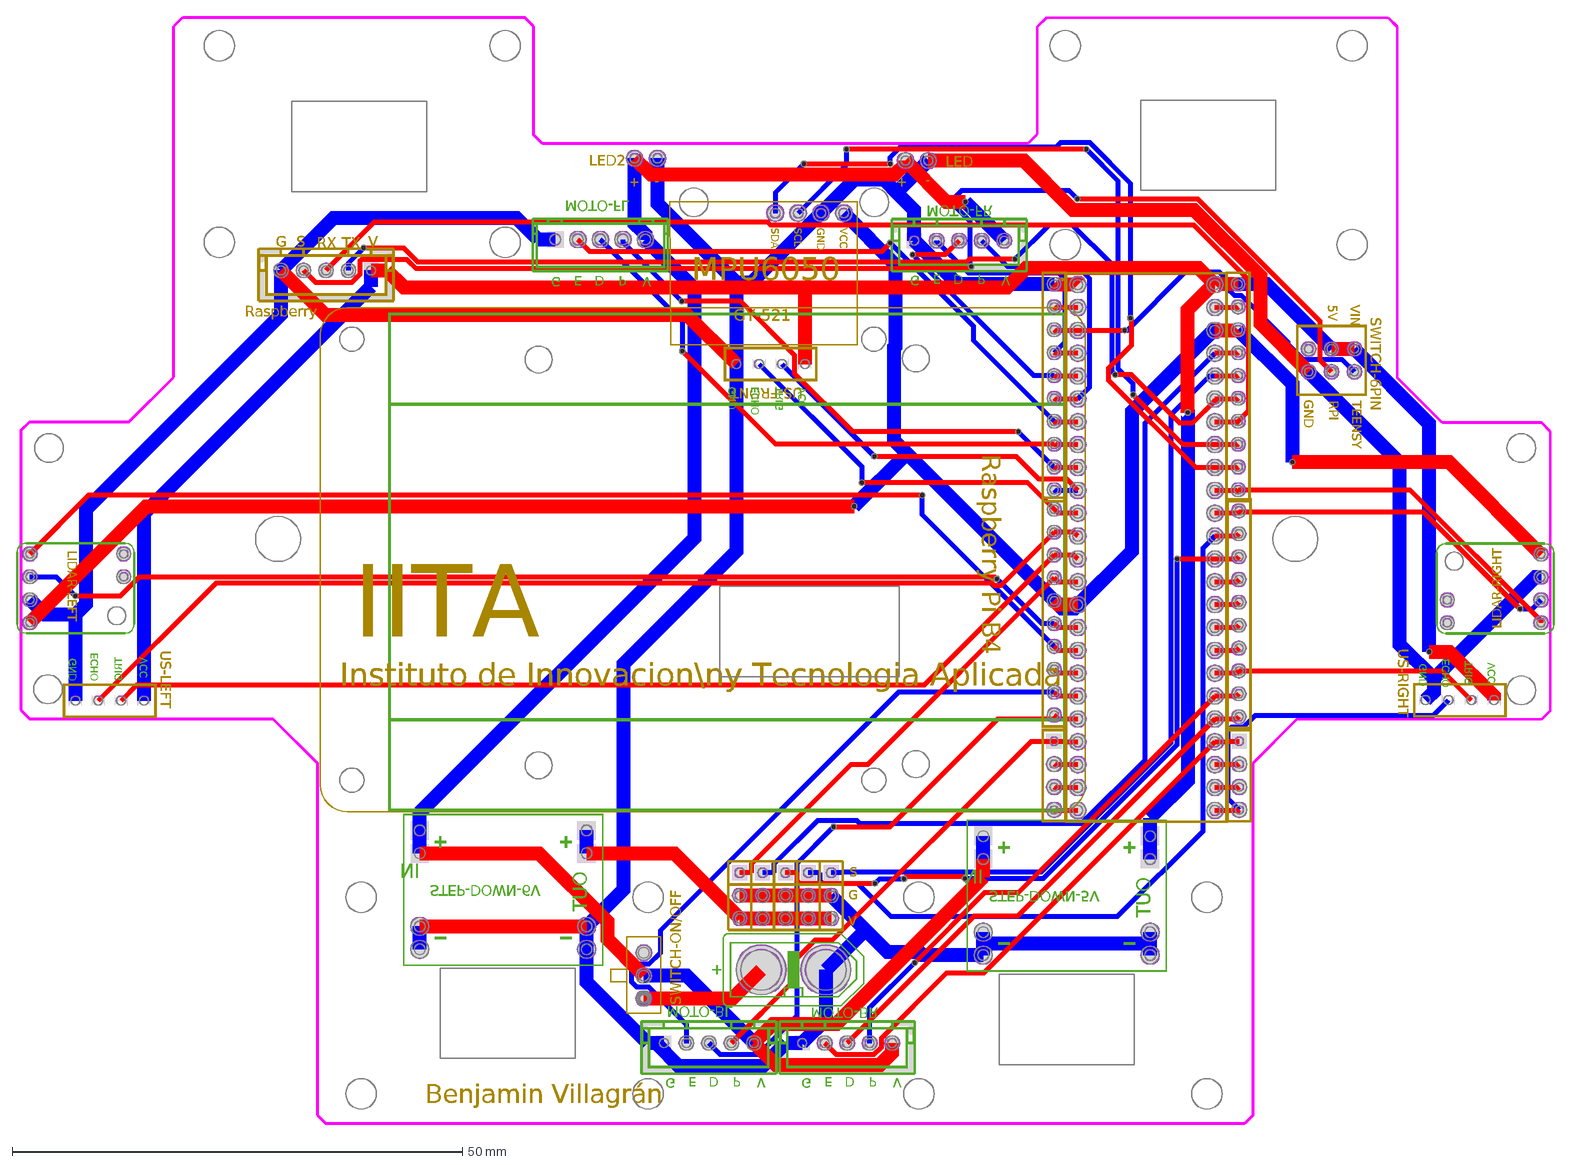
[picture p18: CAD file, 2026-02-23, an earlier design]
hardware/electronics/_legacy/ELECTRONICA/AUTOCAD_PCB/BOCETO DE PCB.dxf
G
V
E
D
P
VIN
TEENSY
GND
RPI
5V
-
+
S
Instituto de Innovacion\ny Tecnologia Aplicada
IITA
TX
RX
Benjamin Villagrán
STEP-DOWN-5V
IN
OUT
STEP-DOWN-6V
LIDAR-LEFT
GPIO1
XSHUT
SDA
SCL
LIDAR-RIGHT
MOTO-FL
MOTO-BL
MOTO-FR
MOTO-BR
Raspberry
Raspberry Pi B4
LED
LED2
MPU6050
VCC
GY-521
SWITCH-6PIN
SWITCH-ON/OFF
US-LEFT
TRIG
ECHO
US-RIGHT
US-FRONT

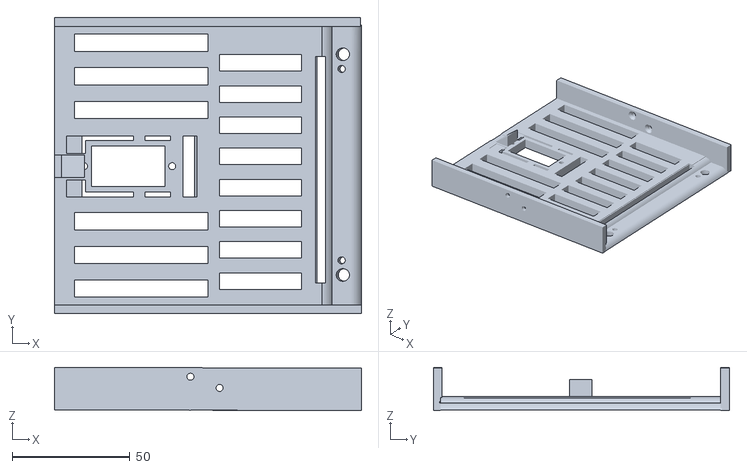
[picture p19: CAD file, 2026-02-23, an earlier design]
hardware/mechanical/_legacy/CAD/STLS/BASE CAJITA.stl
130.5 x 126.0 x 18.4

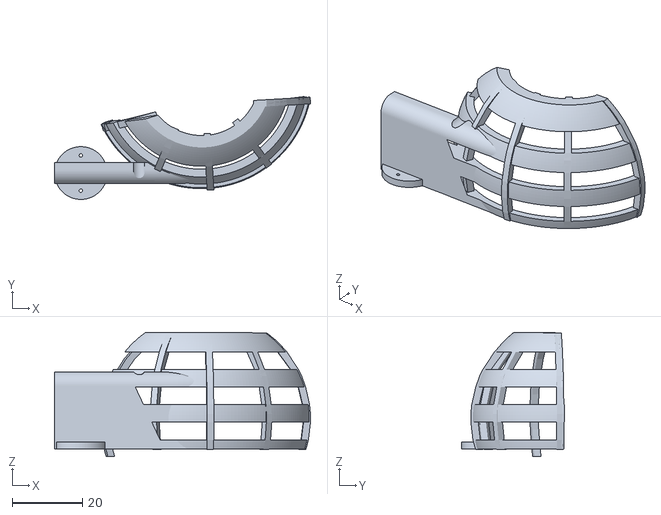
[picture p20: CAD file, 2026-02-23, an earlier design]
hardware/mechanical/_legacy/CAD/STLS/Aleta(izquierda).stl
72.8 x 29.2 x 35.4

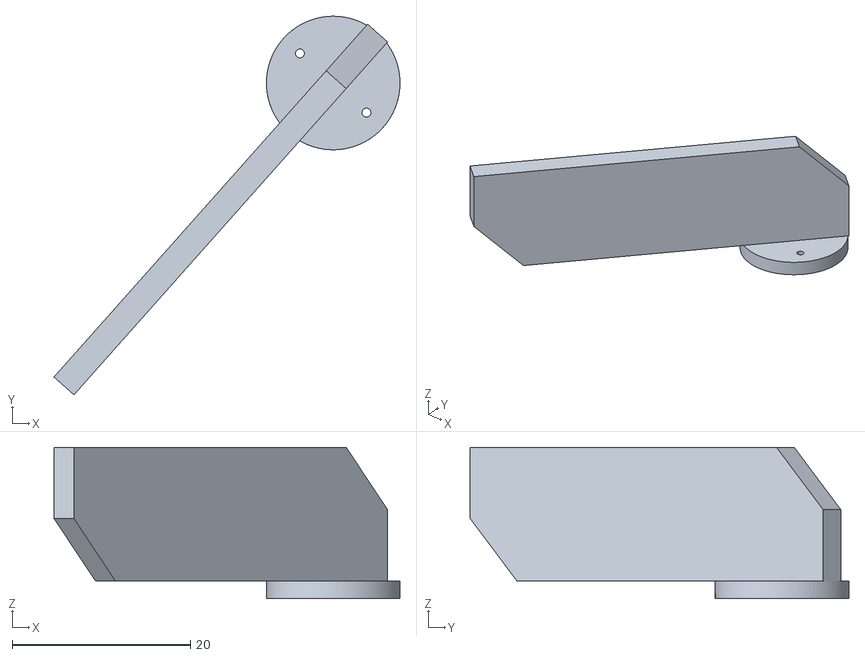
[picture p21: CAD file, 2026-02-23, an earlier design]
hardware/mechanical/_legacy/CAD/STLS/pala.stl
38.8 x 42.5 x 17.0

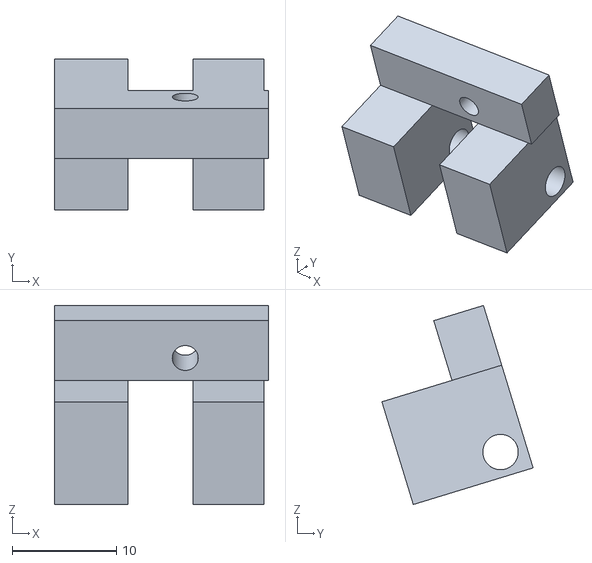
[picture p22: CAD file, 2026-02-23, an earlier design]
hardware/mechanical/_legacy/CAD/STLS/enganche.stl
20.6 x 14.5 x 19.1

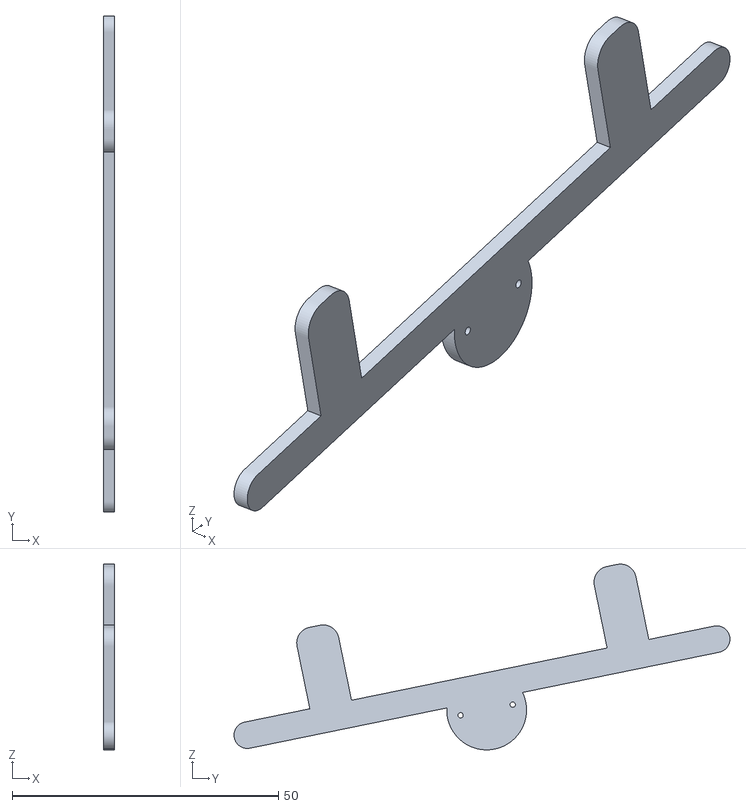
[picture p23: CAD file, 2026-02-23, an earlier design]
hardware/mechanical/_legacy/CAD/STLS/controlador_pelotas.stl
2.00 x 93.2 x 34.9

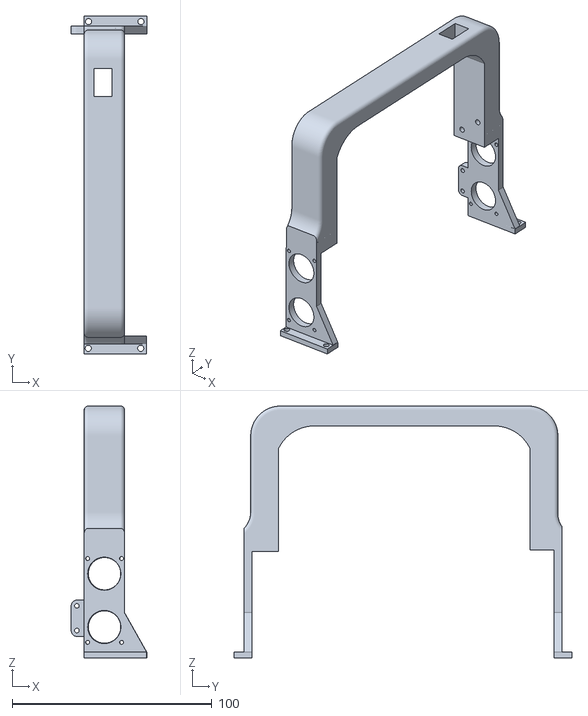
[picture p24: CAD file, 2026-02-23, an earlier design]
hardware/mechanical/_legacy/CAD/STLS/ultrasoniDOS.stl
37.9 x 169.4 x 126.3

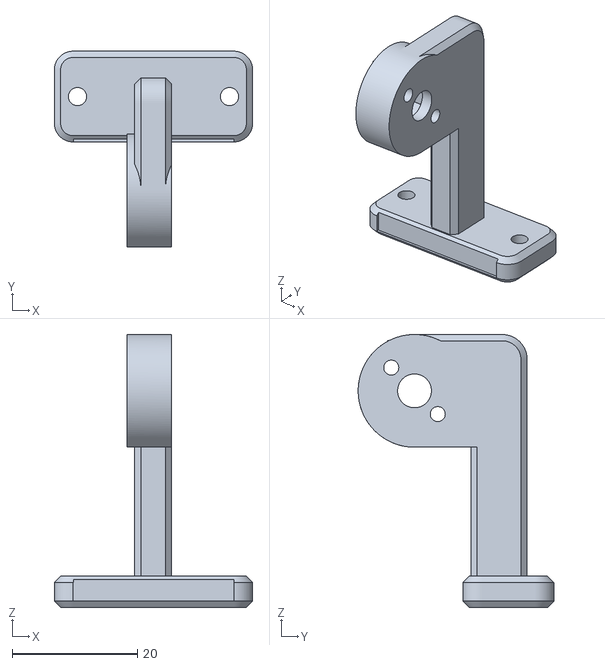
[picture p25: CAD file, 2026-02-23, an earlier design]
hardware/mechanical/_legacy/CAD/STLS/Extensión_servo.stl
31.7 x 31.2 x 43.6

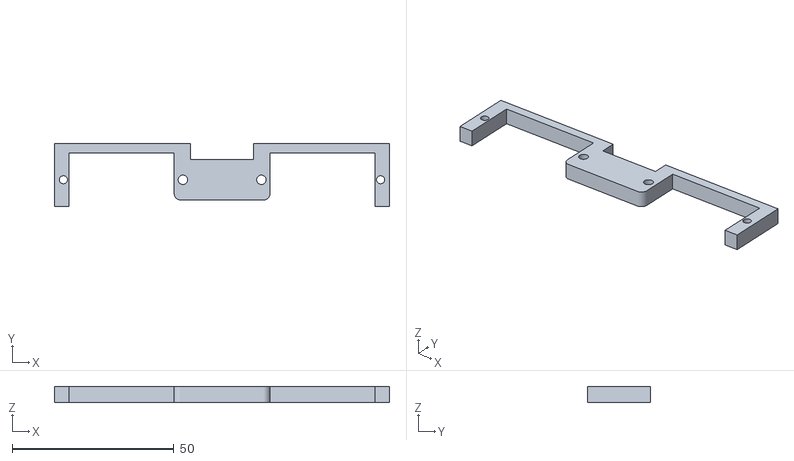
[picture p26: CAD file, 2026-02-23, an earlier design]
hardware/mechanical/_legacy/CAD/STLS/brazo_servos.stl
103.6 x 19.5 x 5.08

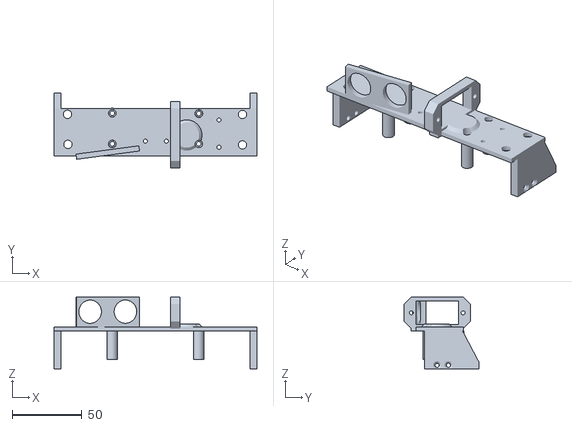
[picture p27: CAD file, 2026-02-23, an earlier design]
hardware/mechanical/_legacy/CAD/STLS/Servos_corregido.stl
146.0 x 53.8 x 51.6

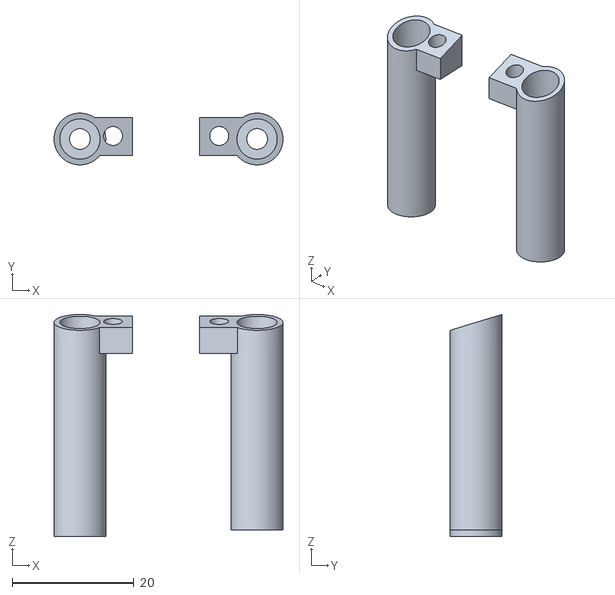
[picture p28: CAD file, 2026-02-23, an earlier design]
hardware/mechanical/_legacy/CAD/STLS/Tubitos_juntos.stl
37.6 x 8.50 x 36.4

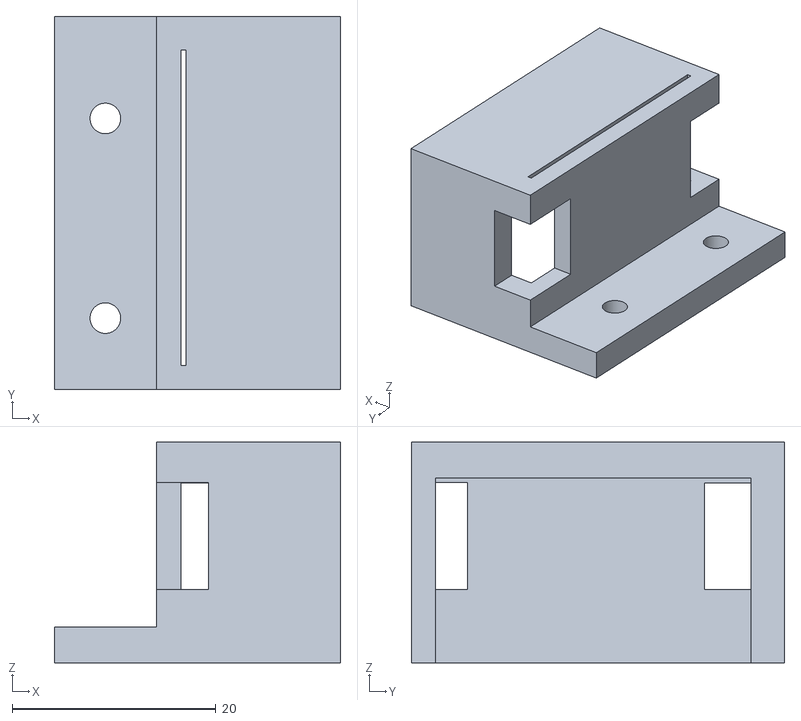
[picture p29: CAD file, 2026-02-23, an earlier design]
hardware/mechanical/_legacy/CAD/STLS/casco de servo.stl
28.1 x 36.6 x 21.7

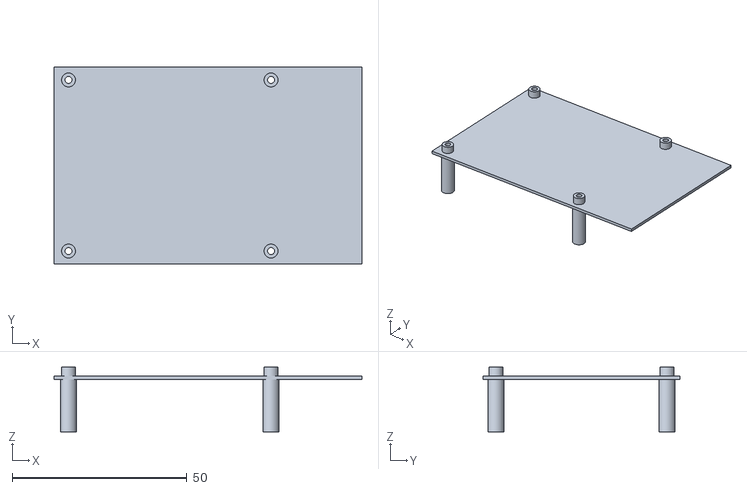
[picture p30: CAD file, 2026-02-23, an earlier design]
hardware/mechanical/_legacy/CAD/STLS/carcasa_rapsberry.stl
88.2 x 56.3 x 18.5

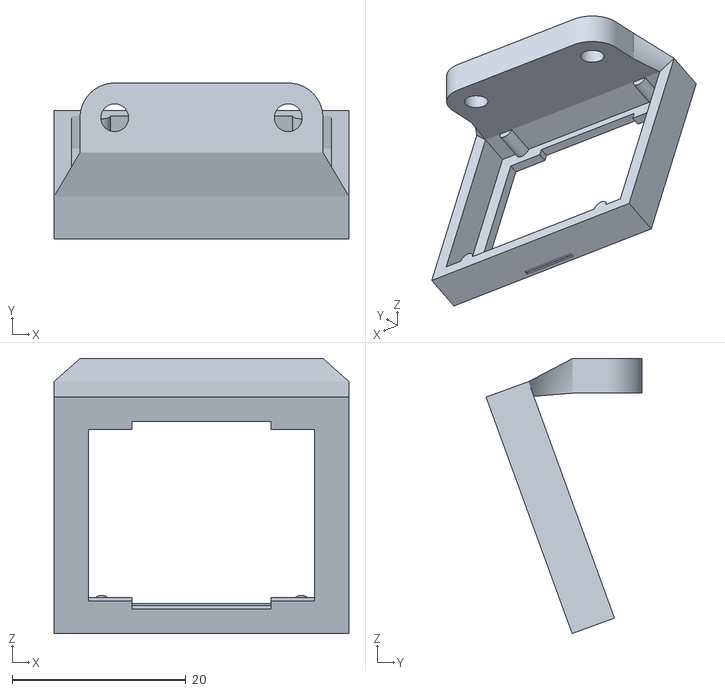
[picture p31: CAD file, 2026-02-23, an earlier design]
hardware/mechanical/_legacy/CAD/STLS/Soprte-de-camara.stl
34.0 x 18.0 x 31.7

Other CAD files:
hardware/mechanical/_legacy/CAD/STLS/motormount v2 thin.stl
hardware/mechanical/_legacy/CAD/STLS/motormount v2.stl
hardware/mechanical/_legacy/CAD/STLS/Aleta.stl
hardware/mechanical/_legacy/CAD/STLS/Motor_L_corregido.stl
hardware/mechanical/_legacy/CAD/STLS/Base.stl
hardware/mechanical/_legacy/CAD/STLS/SoporteMotorDelantero.stl
hardware/mechanical/_legacy/CAD/STLS/Tubitos_6diam.stl
hardware/mechanical/_legacy/CAD/STLS/agarra_bateria.stl

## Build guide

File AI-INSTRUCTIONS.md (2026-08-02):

# Instrucciones para Asistentes de IA

Este repositorio sigue el estándar ICRS v1.1 L2 (IITA Competition Repository Standard).

## Estructura

- `software/teensy/firmware/`: Proyecto PlatformIO para Teensy 4.1
- `software/raspberry/`: Código Python para Raspberry Pi 4B
- `hardware/`: Electrónica (PCB, esquemáticos) y mecánica (CAD, STL)
- `docs/es/`: Documentación fuente en español
- `docs/en/`: Mirror auto-generado en inglés (NO EDITAR). ⏸ **Autotraducción SUSPENDIDA el 2026-08-02** — la carpeta quedó congelada y está desactualizada respecto de `docs/es/`. Cómo reactivarla: cabecera de `.github/workflows/translate-docs.yml`.

## Reglas

1. Siempre vincular cambios a un Issue.
2. Usar Conventional Commits.
3. No hacer push directo a `main`.
4. Documentar en `docs/es/` (español es fuente de verdad).
5. Declarar uso de IA en los PRs.
6. Hardware versionado por revisiones (`rev-a`, `rev-b`, etc.).

## Contexto técnico

- Teensy 4.1 controla motores, sensores y servos.
- Raspberry Pi 4B corre visión (OpenCV + YOLO ONNX).
- Comunicación serial UART a 115200 baudios.
- Protocolo: [255, speed, 254, angle, 253, green_state, 252, silver_line]

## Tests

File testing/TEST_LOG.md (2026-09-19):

# TEST_LOG - Bitacora de tests IITA RCJ 2026

**Equipo:** IITA Salta  
**Competencia:** RoboCupJunior Rescue Line 2026  
**Uso:** evidencia directa para TDP, poster y video.

Cada ensayo se anota con ID secuencial `T-XXX`, categoria entre corchetes y resultado claro: `PASS`, `PARTIAL` o `FAIL`.

---

## 1. Indice por categoria

### `[MECH]` - Mechanical reliability (TDP T7)

| ID | Fecha | Titulo | Resultado |
|---|---|---|---|
| T-001 | 2026-05-23 | Medicion fisica inicial con robot completo | PASS |

### `[ELEC]` - Electronic reliability (TDP T11)

| ID | Fecha | Titulo | Resultado |
|---|---|---|---|
| T-001 | 2026-05-23 | Medicion fisica inicial con robot completo | PASS/PARTIAL |

### `[SW]` - Software reliability (TDP T14)

| ID | Fecha | Titulo | Resultado |
|---|---|---|---|
| T-002 | 2026-05-23 | FPS real y transicion de estados desde systemd | PASS |
| T-009 | 2026-08-31 | Codos tomados con maniobra de recuperacion de linea | PASS |

### `[PERF]` - Performance evaluation (TDP T15)

| ID | Fecha | Titulo | Resultado |
|---|---|---|---|
| T-001 | 2026-05-23 | Medicion fisica inicial con robot completo | PASS/PARTIAL |
| T-002 | 2026-05-23 | FPS real y transicion de estados desde systemd | PASS |
| T-009 | 2026-08-31 | Codos tomados con maniobra de recuperacion de linea | PASS |

---

## 2. Convenciones

- **ID:** `T-001`, `T-002`, secuencial y sin reutilizar.
- **Fecha:** `YYYY-MM-DD`, fecha real del ensayo.
- **Categoria:** uno o dos tags, por ejemplo `[SW]` o `[MECH][PERF]`.
- **Resultado:** `PASS`, `PARTIAL` o `FAIL`.
- **Tester:** nombre o usuario GitHub de quien ejecuto.
- **Robot rev:** SHA corto, branch o `rev-current`.
- **Issue/PR:** link o numero de issue si verifica un fix o destapa un bug.
- **Evidencia:** foto, video, log serial, captura de pantalla, medicion o archivo relacionado.

---

## 3. Plantilla para nueva entrada

Copiar este bloque al final de la seccion 4 y agregar una fila en el indice.

```markdown
## T-XXX - YYYY-MM-DD - [CAT] Titulo corto descriptivo

**Tester:** @handle  
**Robot rev:** rev-current  
**Pista / banco:** sala IITA / pista oficial / mesa de electronica  
**Issue/PR relacionado:** #NNN

**Objetivo.** Una oracion con lo que se queria verificar.

**Setup.**
- Bateria: X.X V al arranque, X.X V al final.
- Iluminacion: fluorescente / mixta / LED zona / natural.
- Pista o banco: descripcion breve.
- Firmware commit: `<sha corto>`.
- RPi commit/modelo: `<sha corto>` / `<modelo usado>`.
- Modo RPi: headless / debug / grabacion.

**Procedimiento.**
1. Paso 1.
2. Paso 2.
3. Paso 3.

**Resultado.**

| Metrica | Esperado | Obtenido | OK |
|---|---|---|---|
| ... | ... | ... | PASS/PARTIAL/FAIL |

**Evidencia.**
- Video:
- Foto:
- Log:
- Otro:

**Conclusion.** Que paso realmente y que se aprendio.

**Accion.**
- Issue abierto/cerrado:
- Re-test programado:
- Cambio de hardware/software:
```

---

## 4. Entradas

### T-001 - 2026-05-23 - `[MECH][ELEC][PERF]` Medicion fisica inicial con robot completo

**Tester:** Benjamin Villagran  
**Robot rev:** rev-current  
**Pista / banco:** robot completo en pista/banco de prueba  
**Issue/PR relacionado:** evidencia para TDP 2026

**Objetivo.** Medir valores fisicos que no se pueden obtener del codigo para completar la evidencia del TDP: autonomia, estabilidad de bateria, precision de `runDistance()` y precision de `runAngle()`.

**Setup.**
- Bateria: 12.6 V al arranque.
- Iluminacion: no registrada.
- Pista o banco: prueba con robot completo.
- Firmware commit: `rev-current`.
- RPi commit/modelo: `rev-current` / modelo de produccion.
- Modo RPi: programa completo corriendo.

**Procedimiento.**
1. Encender el robot con bateria cargada y registrar voltaje inicial.
2. Dejar el robot encendido en reposo durante 5 minutos y registrar voltaje.
3. Ejecutar movimiento continuo hasta que la bateria llegue a 10.5 V.
4. Ejecutar prueba de estres durante 10 minutos con programa completo, motores a `speed = 60` y secuencia de pickup.
5. Ejecutar pruebas de `runDistance()` en distancias cortas y largas.
6. Ejecutar pruebas de `runAngle()` y verificar si el robot corta dentro de la tolerancia de giro.

**Resultado.**

| Metrica | Esperado | Obtenido | OK |
|---|---|---|---|
| Voltaje inicial bateria 3S | cerca de carga completa | 12.6 V | PASS |
| Caida en reposo 5 min | sin caida significativa | 12.6 V -> 12.5 V | PASS |
| Autonomia continua hasta 10.5 V | mantener funcionamiento prolongado | 1 h hasta 10.5 V | PASS |
| Estres motores + pickup | resistir carga alta sin evidencia de fallo | 10 min con programa completo, motores a `speed = 60` y pickup continuo; caida de 1.4 V respecto al inicio de la prueba | PASS |
| Error `runDistance()` en distancia corta | bajo y repetible | aproximadamente 1 cm | PASS |
| Error `runDistance()` en distancia mayor | bajo y repetible | aproximadamente 1-2 cm | PASS |
| Error `runAngle()` | detenerse dentro de la tolerancia IMU de +/-1 grado | frena al grado | PASS |

**Evidencia.**
- Video/foto: opcional para PDF/poster; las mediciones numericas ya fueron volcadas al TDP.
- Log: mediciones reportadas por el equipo durante sesion con robot a mano.
- Otro: usar esta entrada como fuente de la tabla de resultados fisicos del TDP.

**Conclusion.** El robot mostro buena estabilidad electrica en reposo, autonomia cercana a 1 h hasta 10.5 V y precision mecanica suficiente para documentar la calibracion de 25 counts/cm. `runAngle()` confirma la tolerancia de giro de aproximadamente +/-1 grado. La prueba de estres de 10 minutos cerro sin evidencia de fallo y con una caida de 1.4 V bajo exigencia alta; si se toma el arranque de 12.6 V como referencia, el final derivado es aproximadamente 11.2 V.

**Accion.**
- Si queda tiempo antes del PDF final, repetir el estres con hora de inicio/fin y voltaje inicial/final escritos en video o planilla.
- Completar conteos estadisticos opcionales de pickup/deposito si se quiere convertir la validacion funcional en tasa X/20.

---

### T-002 - 2026-05-23 - `[SW][PERF]` FPS real y transicion de estados desde systemd

**Tester:** Benjamin Villagran  
**Robot rev:** rev-current  
**Pista / banco:** robot completo ejecutando el service de Raspberry Pi  
**Issue/PR relacionado:** evidencia para TDP 2026

**Objetivo.** Verificar velocidad real del programa ejecutado como service y confirmar una transicion Teensy -> Raspberry Pi durante la mision.

**Setup.**
- Bateria: no registrada en esta prueba.
- Iluminacion: no registrada.
- Pista o banco: robot encendido con programa completo.
- Firmware commit: `rev-current`.
- RPi commit/modelo: `rev-current` / modelo TFLite de produccion.
- Modo RPi: `systemd` service, salida capturada con `journalctl`.

**Procedimiento.**
1. Reiniciar/ejecutar el service de Raspberry Pi.
2. Esperar warmup del modelo TFLite.
3. Dejar el robot en `estado=linea` durante mas de 30 s.
4. Registrar el log `[LINE-FPS]`.
5. Ejecutar flujo de rescate/deposito hasta recibir el byte `0xF8` desde Teensy.
6. Registrar logs `[HEADLESS] FPS` durante `estado=depositar`.

**Resultado.**

| Metrica | Esperado | Obtenido | OK |
|---|---|---|---|
| Service inicia TFLite y warmup | warmup completo antes de competir | `Warmup completado.` | PASS |
| FPS real de line following | estable durante 30 s | `[LINE-FPS] avg=91.33` | PASS |
| FPS rescue/deposit AI loop | estable con TFLite + anti-flash/AGCWD/tracker | 22.25-22.40 FPS | PASS |
| Transicion rescate -> depositar | Teensy envia `0xF8` y RPi cambia estado | `Llego 248 -> terminar rescate y cambiar a depositar` | PASS |
| Telemetria UART durante service | frames enviados siguen aumentando | `frames_sent` sube de 1 a 2204 durante linea | PASS |

**Evidencia.**
- Log line following: `[LINE-FPS] avg=91.33`.
- Log rescue/deposit: `[HEADLESS] FPS ~ 22.40`, `22.37`, `22.34`, `22.32`, `22.29`, `22.27`, `22.25`.
- Log de transicion: `Llego 248 -> terminar rescate y cambiar a depositar`.
- Fuente: `journalctl` del service de Raspberry Pi.

**Conclusion.** El programa no solo corre desde el service, sino que mantiene una tasa alta de linea y una tasa estable de rescate/deposito con TFLite, anti-flash, AGCWD y tracker activos. Tambien se verifico una transicion real de estado desde Teensy hacia Raspberry Pi.

**Accion.**
- Adjuntar captura o copia del `journalctl` al paquete final si el formato de entrega lo permite.
- Pickup, deposito, anti-flash con linterna y paredes/fondos de colores quedaron registrados funcionalmente en T-003.

---

### T-003 - 2026-05-23 - `[MECH][SW][PERF]` Validacion funcional de pista completa, deposito y vision robusta

**Tester:** Benjamin Villagran  
**Robot rev:** rev-current  
**Pista / banco:** pista completa con robot final  
**Issue/PR relacionado:** evidencia final para TDP 2026

**Objetivo.** Registrar validaciones funcionales que cierran los puntos pendientes de manipulacion de victimas, deposito con finales de carrera, anti-flash con linterna y modelo final con fondos/paredes de colores.

**Setup.**
- Bateria: misma sesion de pruebas del robot completo.
- Iluminacion: prueba con linterna fuerte para estresar anti-flash.
- Pista o banco: pista completa.
- Firmware commit: `rev-current`.
- RPi commit/modelo: `rev-current` / `/home/iita/Documentos/best (2)_float32.tflite`.
- Modo RPi: programa completo corriendo desde Raspberry Pi de IITA.

**Procedimiento.**
1. Ejecutar pista completa con las 3 victimas/pelotas disponibles.
2. Verificar que el mecanismo pueda recogerlas en una misma pasada y mantenerlas para la secuencia de rescate.
3. Ejecutar deposito con finales de carrera izquierdo y derecho (`FCL`/`FCR`).
4. Activar linterna fuerte y verificar que anti-flash + AGCWD mantengan detecciones utiles.
5. Validar por clase el modelo final TFLite entrenado con estres de linterna y fondos/paredes de colores diferentes.

**Resultado.**

| Metrica | Esperado | Obtenido | OK |
|---|---|---|---|
| Pickup en pista completa | recoger victimas sin reiniciar mecanismo | recoge las 3 pelotas en una sola pasada de pista completa | PASS |
| Retencion/flujo de rescate | no perder victimas despues del pickup | las 3 pelotas permanecen manejables para la secuencia de rescate | PASS |
| Deposito con FCL/FCR | alinear con finales de carrera derecho e izquierdo | deposito funciona correctamente usando finales de carrera derecho e izquierdo | PASS |
| Victima negra bajo paredes/iluminacion variable | deteccion estable | funciona correctamente incluso con paredes de distintos colores | PASS |
| Zona de deposito roja bajo paredes/iluminacion variable | deteccion estable sin confundirse con fondos | funciona correctamente incluso con paredes de distintos colores | PASS |
| Victima plateada con reflejo de linterna | mantener deteccion pese a highlights | funciona muy bien a pesar del reflejo fuerte de la linterna | PASS |
| Zona verde con linterna/reflejo | detectar correctamente aunque sea el caso mas dificil | sigue funcionando correctamente, pero agrega aproximadamente 20 s a la zona de rescate, sin contar salida | PASS |
| Modelo final en Raspberry | usar modelo entrenado con linterna y fondos/paredes de colores | `/home/iita/Documentos/best (2)_float32.tflite` cargado en la Raspberry de IITA funciona correctamente en las pruebas del equipo | PASS |

**Evidencia.**
- Video: recomendado para anexar si se usa en el PDF/poster.
- Foto: imagen de prueba con linterna fuerte sobre la zona de rescate; copiar a `docs/tdp/assets/` si se decide usarla como figura.
- Log: observacion de prueba fisica reportada por Benjamin durante la sesion con robot.
- Otro: el modelo final corresponde al path de produccion de la Raspberry: `/home/iita/Documentos/best (2)_float32.tflite`.

**Conclusion.** La validacion funcional muestra que el mecanismo de rescate ya puede recoger las 3 pelotas en pista completa, que el deposito con finales de carrera izquierdo/derecho esta operativo y que la vision robusta con anti-flash/modelo entrenado para linterna y fondos de colores funciona en el robot real. La clase mas afectada por el destello fue la zona verde: no fallo, pero aumento el tiempo de la zona de rescate aproximadamente 20 s, sin contar la salida. Para una tabla estadistica mas fuerte, el siguiente refinamiento seria repetir pickup/deposito en 10-20 intentos y anotar la tasa exacta.

**Accion.**
- Registrar un conteo X/20 de pickup y deposito si hay tiempo antes del PDF final.
- Guardar video corto de anti-flash con linterna y pista completa como evidencia visual para el TDP/poster.

---

### T-004 - 2026-05-23 - `[SW][PERF]` Regression fix: AGCWD-only vs anti-flash + 100-epoch model

**Tester:** Benjamin Villagran  
**Robot rev:** rev-current  
**Pista / banco:** zona de rescate con linterna fuerte, obstaculos visuales/reflejos y fondos/paredes variables  
**Issue/PR relacionado:** evidencia problema -> fix -> re-test para TDP 2026

**Objetivo.** Documentar una falla real de la version anterior de vision y el cambio que la resolvio. La version anterior usaba AGCWD sin el modelo reentrenado de 100 epochs y no era suficientemente robusta: en ciertas condiciones generaba falsos positivos asociados a zonas de deposito. La version final combina anti-flash, AGCWD y el modelo entrenado 100 epochs con estres de linterna, fondos/paredes de colores y augmentations.

**Setup.**
- Pipeline anterior: AGCWD sin el entrenamiento final de 100 epochs.
- Pipeline final: `anti_flash_preprocess()` + AGCWD + `/home/iita/Documentos/best (2)_float32.tflite`.
- Iluminacion: linterna fuerte impactando la zona de rescate y generando reflejos visibles.
- Condicion visual: obstaculos/reflejos en campo de vision, paredes/fondos variables.
- Modo RPi: ventana debug `Optimizado` con FPS visible.

**Procedimiento.**
1. Ejecutar/analizar el comportamiento de la version anterior con AGCWD solamente.
2. Registrar que el pipeline anterior podia generar falsos positivos en zonas de deposito bajo reflejos/fondos dificiles.
3. Ejecutar el pipeline final con anti-flash + AGCWD + modelo final de 100 epochs.
4. Verificar que la deteccion se mantiene estable a pesar de reflejos y obstaculos visuales.
5. Registrar los FPS visibles del debug como evidencia de que la deteccion seguia corriendo en tiempo real.

**Resultado.**

| Metrica | Pipeline anterior | Pipeline final | OK |
|---|---|---|---|
| Falsos positivos en zonas de deposito | presentes en la version AGCWD-only / modelo anterior | no observados en la prueba final reportada | PASS |
| Estabilidad con linterna/reflejos | inestable en casos dificiles | deteccion se mantiene pese al impacto fuerte de la linterna | PASS |
| Estabilidad con obstaculos visuales | podia confundir elementos del entorno | la caja se mantiene sobre el objetivo relevante en los screenshots de debug | PASS |
| FPS debug observado | no usado como evidencia final | aproximadamente 16.14-16.20 FPS en la ventana `Optimizado` | PASS |

**Evidencia.**
- Screenshots: tres capturas de la ventana `Optimizado` con FPS `16.14`, `16.17` y `16.20 [AGCWD]`, caja de deteccion persistente y reflejos/obstaculos visibles.
- Foto/video: recomendado copiar las capturas a `docs/tdp/assets/` si entran en el PDF final.
- Log: observacion reportada por el equipo durante prueba de vision en el robot.
- Otro: el fix combina un cambio de preprocesamiento (`anti_flash_preprocess()` antes de AGCWD) con un cambio de datos/modelo (100 epochs con linterna y paredes/fondos de colores).

**Conclusion.** Este caso es la evidencia mas clara de iteracion de IA: el problema no era solo de umbrales, sino de distribucion de datos y estabilidad ante reflejos. AGCWD solo mejoraba brillo, pero no eliminaba todos los falsos positivos. El sistema final resolvio el caso observado al combinar compresion de reflejos, normalizacion AGCWD y un modelo reentrenado con ejemplos de linterna/fondos dificiles.

**Accion.**
- Usar este caso como narrativa corta en Performance Evaluation: problema -> diagnostico -> fix -> re-test.
- Si el PDF tiene espacio, incluir una captura como figura de evidencia; si no, dejarla como respaldo en el TEST_LOG.

---

### T-005 - 2026-05-23 - `[MECH][SW][PERF]` Pickup/deposit success-rate sample

**Tester:** Benjamin Villagran  
**Robot rev:** rev-current  
**Pista / banco:** pista/zona de rescate con robot final  
**Issue/PR relacionado:** evidencia estadistica final para TDP 2026

**Objetivo.** Convertir la validacion funcional de T-003 en una muestra estadistica corta para pickup y deposito, de forma que el TDP no dependa solo de observaciones cualitativas.

**Setup.**
- Mecanismo: garra, almacenamiento y deposito final.
- Vision: modelo final `/home/iita/Documentos/best (2)_float32.tflite`.
- Condicion especial: se uso una cinta reflectiva con diametro similar a la pelota plateada real como proxy de prueba; una parte no quedo perfectamente pegada al piso.

**Procedimiento.**
1. Ejecutar 10 intentos de pickup en la zona de rescate.
2. Registrar exitos/fallos.
3. Ejecutar 10 intentos de deposito usando la alineacion con finales de carrera.
4. Registrar exitos/fallos.
5. Analizar el origen del fallo de pickup observado.

**Resultado.**

| Metrica | Esperado | Obtenido | OK |
|---|---|---|---|
| Pickup success rate | >=80% en muestra corta | 8/10 | PASS |
| Deposit success rate | >=90% en muestra corta | 10/10 | PASS |
| Causa principal del fallo de pickup | identificar si es mecanica, vision o artefacto de prueba | falso positivo de pelota plateada causado por cinta reflectiva de diametro similar a la pelota real; la cinta no estaba perfectamente pegada al piso | PASS |
| Detecciones restantes en suelo | mantener detecciones utiles despues del artefacto | las demas detecciones del suelo funcionaron muy bien | PASS |

**Evidencia.**
- Video: recomendado si se usa en el PDF/poster.
- Foto: recomendado si se quiere mostrar el artefacto de cinta reflectiva.
- Log: medicion reportada por el equipo durante prueba final.
- Otro: usar esta entrada para la fila de pickup/deposito de la Tabla 10.

**Conclusion.** El deposito ya esta muy solido en la muestra corta: 10/10 con finales de carrera. El pickup alcanzo 8/10; el problema observado no fue una falla general del mecanismo, sino un falso positivo provocado por una cinta reflectiva usada como sustituto de pelota plateada. Esa cinta imitaba el brillo y diametro de la pelota, pero al no estar perfectamente pegada al piso genero una deteccion enganosa. Con las otras detecciones del suelo, el sistema funciono correctamente.

**Accion.**
- Para el PDF, reportar pickup 8/10 y deposito 10/10 con una nota breve sobre el artefacto de cinta reflectiva.
- En futuras pruebas, usar pelotas plateadas reales o pegar completamente los proxies reflectivos al piso para evitar falsos positivos no representativos.

---

### T-006 - 2026-05-23 - `[MECH][ELEC][SW][PERF]` Terrain, ramp and exit-search evaluation

> Nota posterior: la limitacion de salida/evacuacion registrada en esta prueba fue re-testeada y cerrada en T-008 con un video completo donde el robot sale de la zona de rescate.

**Tester:** Benjamin Villagran  
**Robot rev:** rev-current  
**Pista / banco:** pista de linea + rescate con rampas, sube-baja y obstaculos tipo palillos  
**Issue/PR relacionado:** evidencia de confiabilidad mecanica, sensores y limitaciones restantes para TDP 2026

**Objetivo.** Evaluar el comportamiento del robot en pista completa, rampas, sube-baja y obstaculos visuales/fisicos. Documentar tambien una limitacion real: la salida/busqueda de salida de la zona de rescate todavia no navega correctamente.

**Setup.**
- Linea y rescate: funcionamiento completo observado.
- Evacuacion/salida: modo de busqueda de salida todavia inestable.
- Sensor de color: APDS9960 con LED de alto brillo en posicion estrategica para confirmar plateado/floor color.
- Vision: camara + modelo final para detecciones de rescate.
- Terreno: rampa lateral, rampa de subida, sube-baja, palillos/obstaculos.

**Procedimiento.**
1. Ejecutar intentos de full course con linea + rescate + salida.
2. Separar el resultado por modulo: linea, rescate y busqueda de salida/evacuacion.
3. Ejecutar rampas laterales y rampa de subida.
4. Registrar falso positivo de plateado producido por camara en subida.
5. Aplicar/verificar correccion con sensor de color APDS9960 + LED de alto brillo.
6. Ejecutar sube-baja y registrar recuperacion despues del golpe.
7. Probar palillos/obstaculos molestando en linea y rescate.
8. Registrar el caso limite de cuadrado verde cubierto en mas del 80%.

**Resultado.**

| Metrica | Esperado | Obtenido | OK |
|---|---|---|---|
| Full course completo | terminar linea + rescate + salida | 0/5; linea y rescate funcionan, pero la busqueda de salida/evacuacion no navega correctamente todavia | FAIL aislado |
| Tiempo normal de rescate | medir rescate sin salida | 2 min 40 s, sin contar salida | PASS |
| Tiempo rescate con linterna | medir penalizacion por reflejo | +20 s respecto al rescate normal, sin contar salida | PASS |
| Rampas laterales | mantener trayectoria | 0/10 | FAIL |
| Rampa de subida | subir sin falso plateado ni perdida | 8/10 despues de correccion con APDS9960 + LED; antes la camara podia detectar falso plateado en subida | PASS parcial |
| Sube-baja | recomponerse despues del golpe | 9/10; el fallo ocurrio cuando despues de la caida brusca habia un cuadrado verde y lo ignoro | PASS |
| Palillos/obstaculos en rescate y linea | seguir funcionando pese a clutter | funciona muy bien | PASS |
| Cuadrado verde tapado >80% | detectar marcador verde aunque este parcialmente cubierto | si el obstaculo tapa mas del 80% del cuadrado verde, el robot lo ignora | Limite identificado |

**Fix aplicado para falso plateado en subida.**
La camara podia confundir la subida con plateado. Se agrego confirmacion por APDS9960 usando un LED de alto brillo en posicion estrategica. El clasificador usa datos RGBC filtrados y reglas de ratio para separar plateado/blanco/rojo antes de caer al matching por minimos cuadrados para otros colores.

Parametros clave extraidos del firmware:
- Integracion APDS: 10 ms.
- Poll de estado: 2 ms.
- Timeout de lectura fresca: 35 ms.
- Filtro: 3 muestras.
- Regla plateado: `C > 1700` y `R/C > 0.240`.
- Regla blanco: `C > 1500` y `R/C <= 0.235`.

**Evidencia.**
- Codigo: `software/teensy/firmware/src/main.cpp`, bloque `known_colors`, `classify_color()`, `update_color_nonblocking()`, `get_color_fresh()`.
- Video/foto: recomendado grabar rampa de subida y sube-baja si se usa en PDF/poster.
- Observacion: el fallo de full course esta aislado a busqueda de salida/evacuacion; no a linea ni rescate.

**Conclusion.** La medicion separa claramente lo que funciona de lo que queda por mejorar. Linea, rescate, pickup/deposito y subida mejoraron con la fusion camara + APDS. El mayor bloqueo real para cerrar full course es la navegacion de salida de rescate/evacuacion. Mecanicamente, el sube-baja es aceptable con 9/10 y recuperacion despues del golpe; la rampa lateral sigue siendo un caso debil con 0/10. El caso de marcador verde tapado >80% se considera limite fisico/visual: si el marcador queda casi oculto, la vision no tiene suficiente informacion.

**Accion.**
- Prioridad tecnica antes de competir: corregir busqueda de salida de rescate/evacuacion.
- Si hay tiempo: repetir rampas laterales despues de ajustar velocidad, centro de masa o estrategia de enfoque.
- En el TDP, reportar esta prueba como evaluacion honesta de modulos y como evidencia del fix APDS+LED para falso plateado.

---
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

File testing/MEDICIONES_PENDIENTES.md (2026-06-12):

# Mediciones fisicas y estado final de evidencia - TDP 2026

Este archivo conserva el checklist de mediciones fisicas que no se pueden obtener del codigo. La mayoria ya fue medida y volcada al TDP; queda como guia para el PDF final y para mejoras opcionales de confianza.

## Estado actual despues de T-001 a T-008

La mayoria de las mediciones criticas ya fueron registradas en `testing/TEST_LOG.md` y volcadas al TDP: FPS de linea, FPS de rescate/deposito, bateria, runtime, `runDistance()`, `runAngle()`, pickup/deposito, railes de alimentacion, anti-flash, paredes de colores, rampas, masa, parametros de impresion 3D, diagramas CAD/reales y full-course retest con salida de rescate.

Pendientes reales antes del PDF final:

- Exportacion/revision del PDF en la plantilla oficial.
- Full-course retest: **cerrado en T-008** con video completo donde el robot sale de la zona de rescate.
- Opcional de alta confianza: caida minima del rail de servos durante pickup y 5 V logic/compute rail bajo vision + Teensy activos.

## Prioridad ALTA (afectan la nota directamente)

### 1. FPS real de vision (5 min)

**Estado:** medido en T-002. Resultado: line-following loop a 91.33 FPS durante una ventana de 30 s desde el service real de Raspberry Pi.

- Agregar al inicio de `Main.py`:

```python
import time
t0 = time.time()
frames = 0
```

- Agregar al final del loop principal:

```python
frames += 1
print(f"FPS: {frames / (time.time() - t0):.1f}")
```

- Correr 30 segundos en modo line following.
- Anotar el FPS promedio.
- Donde va en el TDP: Seccion 4a, reemplaza "camera-loop speed" o cualquier descripcion generica de velocidad.

### 2. Voltaje bajo carga (10 min)

**Estado:** medido en T-001. Ya hay 12.6 V inicial, 12.5 V despues de 5 min en reposo, 1 h hasta 10.5 V en funcionamiento continuo y caida de 1.4 V durante la prueba extrema de 10 min con motores a `speed = 60` + pickup continuo. Si la referencia inicial fue 12.6 V, el final derivado es aproximadamente 11.2 V.

- Multimetro en los bornes de la bateria.
- Medir en reposo con el robot quieto y encendido.
- Medir mientras los 4 motores corren y los 5 servos ejecutan una secuencia de pickup.
- Anotar `V_reposo` y `V_carga`.
- Donde va en el TDP: Seccion 3b y Tabla 9.

### 3. Precision de `runDistance()` (10 min)

**Estado:** medido en T-001. Resultado inicial: error aproximado de 1 cm en distancias cortas y 1-2 cm en distancias mayores.

- Marcar 10 cm, 25 cm y 50 cm en el piso con cinta.
- Correr cada distancia 5 veces.
- Medir con regla el error real.
- Anotar: distancia pedida, media real y error maximo.
- Donde va en el TDP: Tabla 5 y Tabla 8.

### 4. Precision de `runAngle()` (10 min)

**Estado:** medido en T-001. Resultado inicial: el robot frena aproximadamente al grado, consistente con la tolerancia IMU de +/-1.0 grado.

- Pedir 90 grados exactos, 10 veces.
- Medir angulo final con transportador o display de IMU.
- Anotar error promedio y maximo.
- El codigo corta con tolerancia IMU de +/-1.0 grado. Confirmar si se cumple fisicamente.
- Donde va en el TDP: Tabla 5 y Tabla 8.

### 5. Tasa de pickup (10 min)

**Estado:** medido en T-005. Pickup 8/10 en muestra corta. El fallo observado se debio a un falso positivo de una cinta reflectiva usada como proxy de pelota plateada; la cinta tenia diametro similar a la pelota real y no estaba perfectamente pegada al piso. Las demas detecciones del suelo funcionaron muy bien.

- Posicionar victima negra en posicion estandar.
- Ejecutar 10 intentos de pickup.
- Contar exitosos, fallidos y casos en que la victima cae despues.
- Repetir con victima plateada.
- Anotar: X/10 negra, Y/10 plateada.
- Donde va en el TDP: Tabla 8, Seccion 5.

### 5b. Deposito con finales de carrera

**Estado:** medido en T-005. Deposito 10/10 usando finales de carrera derecho e izquierdo (`FCL`/`FCR`).

- Ejecutar deposito a la izquierda 10 veces.
- Ejecutar deposito a la derecha 10 veces.
- Anotar exitosos, fallos de alineacion y fallos de liberacion.
- Donde va en el TDP: Tabla 8, Seccion 5.

## Prioridad MEDIA (mejoran la nota pero no son criticas)

### 5c. Full course, rampas y sube-baja

**Estado:** T-006 documento el fallo anterior de full course 0/5 por busqueda de salida/evacuacion, con linea y rescate funcionando por separado. T-008 cierra el retest principal: el equipo consiguio un video completo donde el robot sale de la zona de rescate despues de la correccion. Rescate normal: 2 min 40 s sin contar salida. Rescate con linterna: +20 s. Rampas laterales: 0/10. Rampa de subida: 8/10 despues del fix con APDS9960 + LED de alto brillo para evitar falso plateado de camara. Sube-baja: 9/10; el fallo ocurrio cuando despues de la caida brusca habia un cuadrado verde y lo ignoro. Palillos/obstaculos funcionan bien salvo cuando tapan mas del 80% del cuadrado verde.

- Prioridad tecnica: repetir 3-5 full courses si se quiere convertir el video exitoso en estadistica.
- Si se repite: separar resultados por modulo para no mezclar linea/rescate, deposito y salida.

### 6. Autonomia de bateria

**Estado:** medido en T-001. Resultado inicial: aproximadamente 1 h de funcionamiento continuo hasta 10.5 V.

- Cargar la bateria completa.
- Correr el robot en line following continuo.
- Anotar cuantos minutos pasan hasta bajar a 10.5 V.
- Donde va: Seccion 3b.

### 7. FPS del detector AI

**Estado:** medido en T-002 para el loop rescue/deposit completo. Resultado: 22.25-22.40 FPS desde `journalctl` con TFLite, anti-flash/AGCWD y tracker activos.

- En modo rescue, agregar un timer alrededor de la llamada de inferencia.
- Anotar ms por inferencia y FPS resultante.
- Donde va: Seccion 4a.

### 8. Validacion anti-flash + AGCWD con linterna fuerte

**Estado:** validado funcionalmente en T-003. Con linterna fuerte, anti-flash + AGCWD funciona. La deteccion de victima negra y zona roja funciona correctamente incluso con paredes de distintos colores; la victima plateada funciona muy bien a pesar del reflejo; la zona verde es la clase mas exigente, pero sigue funcionando y agrega aproximadamente 20 s a la zona de rescate sin contar salida.

- Activar modo rescue con `ENABLE_ANTIFLASH=True`.
- Apuntar una linterna blanca fuerte contra la pared/zona de evacuacion.
- Grabar 30 segundos con y sin destello directo.
- Registrar falsos positivos antes/despues de pasar por `anti_flash_preprocess()` + AGCWD.
- Verificar que la pelota negra y plateada sigan detectandose cuando no quedan totalmente tapadas por el destello.
- Donde va: Seccion 4b, Innovation 3.

### 9. Validacion del modelo nuevo con paredes de colores

**Estado:** validado funcionalmente en T-003 con el modelo final desplegado en la Raspberry de IITA: `/home/iita/Documentos/best (2)_float32.tflite`. El modelo corresponde al entrenamiento de estres con linterna y fondos/paredes de colores diferentes, y funciona correctamente en pruebas del equipo. Negro, plateado y rojo se mantienen robustos; verde funciona pero es el caso mas lento bajo reflejo fuerte. Falta solo registrar una tabla por color si se quiere evidencia estadistica completa.

**Regression fix registrado:** T-004 documenta que la version anterior AGCWD-only/modelo previo al entrenamiento final generaba falsos positivos en zonas de deposito. El pipeline final anti-flash + AGCWD + modelo de 100 epochs corrigio ese caso observado y mantuvo deteccion estable con reflejos/obstaculos visuales.

- Usar la rama que contiene el modelo reentrenado desde Roboflow.
- Confirmar que el entrenamiento usado corresponde a `yolov8n.pt`, 100 epochs, `imgsz=256`, AMP activado, `hsv_s=0.7`, `hsv_v=0.8`, `mosaic=1.0`, `mixup=0.1`, `copy_paste=0.1` y `erasing=0.4`.
- Probar detecciones con pared blanca, marron claro, naranja, amarilla y gris.
- Repetir explicitamente el caso critico: pared naranja fluor + victimas negras + zona roja visible.
- Registrar falsos positivos de `rojo_alto`, falsos negativos de `negro` y estabilidad de `plateado`.
- Confirmar que pelota negra y pelota plateada se mantienen separadas bajo linterna fuerte.
- Anotar si la pared naranja deja de confundirse con la zona de deposito roja.
- Donde va: Seccion 4b, Tabla 8 y dataset robustness snapshot.

## Formato para anotar resultados

Cuando terminen la sesion, abrir `testing/TEST_LOG.md` y agregar una entrada `T-001` con todos los valores medidos.

Usar la plantilla del punto 3 de `testing/TEST_LOG.md`:

```markdown
## T-001 - YYYY-MM-DD - [MECH][ELEC][SW][PERF] Medicion fisica final para TDP

**Tester:** @handle
**Robot rev:** rev-current
**Pista / banco:** sala IITA / pista oficial / mesa de electronica
**Issue/PR relacionado:** #NNN

**Objetivo.** Medir los valores fisicos que no pueden extraerse del codigo para completar la evidencia del TDP.

**Setup.**
- Bateria: X.X V al arranque, X.X V al final.
- Iluminacion: fluorescente / mixta / LED zona / natural.
- Pista o banco: descripcion breve.
- Firmware commit: `<sha corto>`.
- RPi commit/modelo: `<sha corto>` / `<modelo usado>`.
- Modo RPi: headless / debug / grabacion.

**Procedimiento.**
1. Medir FPS real de vision.
2. Medir voltaje en reposo y bajo carga.
3. Ejecutar pruebas de `runDistance()`.
4. Ejecutar pruebas de `runAngle()`.
5. Ejecutar pruebas de pickup negro y plateado.
6. Ejecutar validacion anti-flash + AGCWD con linterna fuerte.
7. Ejecutar validacion del modelo nuevo con paredes de colores.

**Resultado.**

| Metrica | Esperado | Obtenido | OK |
|---|---|---|---|
| FPS real de vision | estable durante 30 s | ... | PASS/PARTIAL/FAIL |
| Voltaje bajo carga | sin reset ni caida critica | ... | PASS/PARTIAL/FAIL |
| Error `runDistance()` | bajo y repetible | ... | PASS/PARTIAL/FAIL |
| Error `runAngle()` | cerca de +/-1.0 grado IMU | ... | PASS/PARTIAL/FAIL |
| Pickup victima negra | 10 intentos | .../10 | PASS/PARTIAL/FAIL |
| Pickup victima plateada | 10 intentos | .../10 | PASS/PARTIAL/FAIL |
| Anti-flash + AGCWD | sin falsos positivos por destello visible | ... | PASS/PARTIAL/FAIL |
| Pared naranja fluor sin falso `rojo_alto` | sin confusion con deposito rojo | ... | PASS/PARTIAL/FAIL |
| Paredes blanca/marron/amarilla/gris | deteccion estable | ... | PASS/PARTIAL/FAIL |

**Evidencia.**
- Video:
- Foto:
- Log:
- Otro:

**Conclusion.** Que paso realmente y que se aprendio.

**Accion.**
- Issue abierto/cerrado:
- Re-test programado:
- Cambio de hardware/software:
```

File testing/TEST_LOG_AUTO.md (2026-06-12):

# Auto-extracted metrics from codebase
# Generated by Codex - values need field validation before TDP submission
# CONFIDENCE levels: exact=in code, derived=calculated, estimated=inferred

This file only contains values that are explicitly present in the codebase or mathematically derivable from those values. It does not contain measured competition performance.

External component evidence from the PCB BOM links is documented in `hardware/electronics/PCB_Main/COMPONENT_SPECS_VERIFIED.md`.

## Extraction ledger

METRIC: Camera source index  
SOURCE: software/raspberry/final_rpi/Main.py:68  
VALUE: 0  
CONFIDENCE: exact  
TEST_LOG_CATEGORY: SW

METRIC: Camera default resolution  
SOURCE: software/raspberry/final_rpi/camthreader.py:5, software/raspberry/final_rpi/camthreader.py:10, software/raspberry/final_rpi/camthreader.py:11  
VALUE: 160 x 120 px  
CONFIDENCE: exact  
TEST_LOG_CATEGORY: SW

METRIC: Active camera FPS cap  
SOURCE: software/raspberry/final_rpi/camthreader.py:12  
VALUE: Not set in active code; CAP_PROP_FPS=60 is commented out  
CONFIDENCE: exact  
TEST_LOG_CATEGORY: SW

METRIC: Line-following frame resize  
SOURCE: software/raspberry/final_rpi/Main.py:763  
VALUE: 160 x 120 px  
CONFIDENCE: exact  
TEST_LOG_CATEGORY: SW

METRIC: YOLO / ZeroDCE inference image size  
SOURCE: software/raspberry/final_rpi/Main.py:82, software/raspberry/final_rpi/Main.py:227, software/raspberry/final_rpi/Main.py:474  
VALUE: 256 x 256 px  
CONFIDENCE: exact  
TEST_LOG_CATEGORY: SW

METRIC: YOLO detection cadence  
SOURCE: software/raspberry/final_rpi/Main.py:325, software/raspberry/final_rpi/Main.py:476  
VALUE: every 3 frames  
CONFIDENCE: exact  
TEST_LOG_CATEGORY: SW

METRIC: YOLO result queue size  
SOURCE: software/raspberry/final_rpi/Main.py:326, software/raspberry/final_rpi/Main.py:444  
VALUE: 2 frames  
CONFIDENCE: exact  
TEST_LOG_CATEGORY: SW

METRIC: AI confidence thresholds  
SOURCE: software/raspberry/final_rpi/Main.py:337, software/raspberry/final_rpi/Main.py:338, software/raspberry/final_rpi/Main.py:339, software/raspberry/final_rpi/Main.py:340, software/raspberry/final_rpi/Main.py:341  
VALUE: class 0=45%, class 1=45%, class 2=50%, class 3=60%  
CONFIDENCE: exact  
TEST_LOG_CATEGORY: SW

METRIC: AI fallback confidence threshold  
SOURCE: software/raspberry/final_rpi/Main.py:500  
VALUE: 50%  
CONFIDENCE: exact  
TEST_LOG_CATEGORY: SW

METRIC: Anti-flash preprocessing enable flag  
SOURCE: software/raspberry/final_rpi/Main.py:229, software/raspberry/final_rpi/Main.py:259, software/raspberry/final_rpi/Main.py:479  
VALUE: ENABLE_ANTIFLASH=True; anti_flash_preprocess() runs before AGCWD in enhance() and on non-detection rescue frames  
CONFIDENCE: exact  
TEST_LOG_CATEGORY: SW

METRIC: Anti-flash highlight detection threshold  
SOURCE: software/raspberry/final_rpi/Main.py:231, software/raspberry/final_rpi/Main.py:237  
VALUE: flash_mask = V >= 215 and S <= 60 in HSV space  
CONFIDENCE: exact  
TEST_LOG_CATEGORY: SW

METRIC: Anti-flash highlight compression  
SOURCE: software/raspberry/final_rpi/Main.py:231, software/raspberry/final_rpi/Main.py:242, software/raspberry/final_rpi/Main.py:243, software/raspberry/final_rpi/Main.py:244, software/raspberry/final_rpi/Main.py:246  
VALUE: GaussianBlur 5x5 soft mask; compressed V = 215 + (V - 215) x 0.45 under alpha mask  
CONFIDENCE: exact  
TEST_LOG_CATEGORY: SW

METRIC: AGCWD high-brightness blend  
SOURCE: software/raspberry/final_rpi/Main.py:204, software/raspberry/final_rpi/Main.py:216, software/raspberry/final_rpi/Main.py:217, software/raspberry/final_rpi/Main.py:218, software/raspberry/final_rpi/Main.py:219  
VALUE: w=0.5; if mean_v > 120, LUT is blended 30% AGCWD and 70% identity; applied with cv2.LUT  
CONFIDENCE: exact  
TEST_LOG_CATEGORY: SW

METRIC: Centering tolerance for victim alignment  
SOURCE: software/raspberry/final_rpi/Main.py:330, software/raspberry/final_rpi/Main.py:636  
VALUE: 8 px  
CONFIDENCE: exact  
TEST_LOG_CATEGORY: SW

METRIC: Rescue close-enough width ratio  
SOURCE: software/raspberry/final_rpi/Main.py:331, software/raspberry/final_rpi/Main.py:647  
VALUE: 0.21 frame width  
CONFIDENCE: exact  
TEST_LOG_CATEGORY: SW

METRIC: Rescue box close-enough width ratio  
SOURCE: software/raspberry/final_rpi/Main.py:332, software/raspberry/final_rpi/Main.py:645  
VALUE: 0.98 frame width  
CONFIDENCE: exact  
TEST_LOG_CATEGORY: SW

METRIC: Evacuation close-enough width ratio  
SOURCE: software/raspberry/final_rpi/Main.py:333, software/raspberry/final_rpi/Main.py:643  
VALUE: 0.68 frame width  
CONFIDENCE: exact  
TEST_LOG_CATEGORY: SW

METRIC: Rescue resume width ratio  
SOURCE: software/raspberry/final_rpi/Main.py:334  
VALUE: 0.18 frame width  
CONFIDENCE: exact  
TEST_LOG_CATEGORY: SW

METRIC: Black mask threshold range  
SOURCE: software/raspberry/final_rpi/Main.py:70, software/raspberry/final_rpi/Main.py:71  
VALUE: lower [0, 0, 0], upper [90, 90, 90]  
CONFIDENCE: exact  
TEST_LOG_CATEGORY: SW

METRIC: Green LAB mask threshold range  
SOURCE: software/raspberry/final_rpi/Main.py:72, software/raspberry/final_rpi/Main.py:73  
VALUE: lower [120, 90, 100], upper [170, 120, 140]  
CONFIDENCE: exact  
TEST_LOG_CATEGORY: SW

METRIC: Silver mask threshold range  
SOURCE: software/raspberry/final_rpi/Main.py:74, software/raspberry/final_rpi/Main.py:75, software/raspberry/final_rpi/Main.py:786  
VALUE: lower [79, 16, 46], upper [168, 28, 79] applied to resized frame  
CONFIDENCE: exact  
TEST_LOG_CATEGORY: SW

METRIC: Red HSV mask threshold range 1  
SOURCE: software/raspberry/final_rpi/Main.py:76, software/raspberry/final_rpi/Main.py:77  
VALUE: lower [0, 84, 54], upper [7, 255, 200]  
CONFIDENCE: exact  
TEST_LOG_CATEGORY: SW

METRIC: Red HSV mask threshold range 2  
SOURCE: software/raspberry/final_rpi/Main.py:78, software/raspberry/final_rpi/Main.py:79  
VALUE: lower [170, 84, 54], upper [179, 255, 200]  
CONFIDENCE: exact  
TEST_LOG_CATEGORY: SW

METRIC: Green detection minimum active pixels  
SOURCE: software/raspberry/final_rpi/Main.py:59, software/raspberry/final_rpi/Main.py:795  
VALUE: 150 active mask pixels  
CONFIDENCE: derived  
TEST_LOG_CATEGORY: SW
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

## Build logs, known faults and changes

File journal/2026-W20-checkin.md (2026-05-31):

# Checkin semanal — Semana W20 (2026-05-16)

> **DOCUMENTO HISTORICO (2026-05-16, semana W20).** Estado de proyecto y regimen vigente: ver `docs/es/ESTADO-ACTUAL-2026-05-31.md`. Las fechas y pendientes de abajo pueden estar superados.
>
> Foto semanal del 16/18-may. Al 2026-05-31: el "T–6 semanas" está vencido (faltan ~4,3); las fechas de fases de abajo (incluidas las DOS variantes del régimen track-dual que conviven en este archivo — cabecera vs. línea de "Decisiones tomadas") quedaron **superadas**. Régimen vigente: **Track A (firmware/comms) ya en gate de Enzo**, **Track B push libre hasta 2026-06-11**, **freeze de código 2026-06-15**. PR #101 (TEST_LOG) **ya está mergeado en main** — abajo aparece como "a un merge de distancia" porque era foto del 16-may. Se preserva como registro.

**T–6 semanas a Incheon** (2026-06-30, 45 días).
**Régimen: gate progresivo con TRACK DUAL por subsistema** (Gustavo 2026-05-16, **+7 días el 2026-05-18** para dar tiempo de cierre al equipo):
- **Track A — firmware/control + comms:** 🟢 push libre ≤2026-05-26 · 🟡 gate Enzo 2026-05-27→06-06 · 🔴 gate Gustavo ≥2026-06-07.
- **Track B — docs + visión (RPi):** 🟢 push libre ≤2026-06-11 · 🟡 gate Enzo ≥2026-06-12.
- **Transversal (NO se movió — atado al mundial):** última semana (06-23→06-29) + mundial = logística, cero código.
- **Hoy (18-may) ambos tracks en push libre.** Track A tiene 8 días de aire (hasta 26-may); Track B hasta 11-jun. La extensión descomprime el firmware/Laureano.

> Primer checkin del régimen (no hay W19 previo para comparar). Generado por el coach director; **sin commitear** — Gustavo revisa.

## Cerrado / en vuelo esta semana
- PR #101 (TEST_LOG.md, ~24 pts TDP) **ready**, a un merge de distancia — máximo leverage abierto.
- Commits de timeouts + fixes claw.cpp en `feature/initialize-testing-log` (pero ver Atascado).
- Auditoría integral de los 3 subsistemas completada (Teensy / RPi visión / comms).
- Skill `rcj-coach-director` + `/coach-checkin` implementadas (PR #100, smoke tests pendientes).
- Reparto por persona materializado en issues #102–#106.

## Atascado / alerta
- 🔴 **Timeouts #59/#60/#61/#62 REVERTIDOS en código** (`cead75e` borró lo de `5bac4a5`). El equipo creía que estaban resueltos. Comentado en los 3 issues + plan en #105. **Riesgo P0 — prioridad #1 real.**
- 🔴 **Triage #91 vence 2026-05-17 (mañana).** Sin cerrar, el equipo entra al freeze sin prioridades.

## Estado por persona

| Persona  | Semáforo | Nota |
|---|---|---|
| Laureano (Laumonteros) | 🔴 | #105: timeouts revertidos sin arrancar — es la prioridad #1 crítica del proyecto |
| Benjamin | 🟡 | #104 (cluster RPi + #68 suyo + gate de banco) definido; depende de kickoff |
| Lucio | 🟡 | Fixes RPi (#65/#66/#73/#64 + V-A→V-F) referenciados en #104; depende de Benjamin/banco |
| Enzo | 🟡 | #106 con deadlines inminentes: merge #101 + cerrar triage #91 mañana |

## Decisiones tomadas esta semana
- **Régimen revisado a gate progresivo con TRACK DUAL** (Gustavo 2026-05-16, reemplaza todo lo anterior): Track A firmware/comms (F1≤05-19 · gate Enzo 05-20 · gate Gustavo 05-31) · Track B docs/visión (libre ≤06-04 · gate Enzo ≥06-05). → memoria + spec + SKILL.md + comando + issues.
- Reordena el énfasis: la deadline dura (19-5) es del frente firmware/Laureano; visión tiene ventana hasta 4-jun.
- Reparto del trabajo por persona en issues separados (#102 agenda, #103 consolidado, #104 Benjamin, #105 Laureano, #106 Enzo).
- Alerta de timeouts revertidos comentada en #60/#61/#62 (autorizada por Gustavo).
- Aclarado: Laureano = Laureano Monteros = `Laumonteros` (una persona).

## Movimientos en el board
- **Entran al `must` (vía triage #91):** 10 quick-wins nuevos (5 confiabilidad: T-A,T-B,V-A,V-E,C-A · 5 performance: V-F,V-D,V-B,V-C,T-C) + re-aplicación de timeouts.
- **Re-priorizado a #1:** timeouts #59/#60/#61/#62 (estaban como "verificar", ahora confirmados revertidos).
- **A evaluar en triage:** 5 temas medio-riesgo (FSM rescate bloqueante, serialEvent5 desfase, Serial5.write(255) colisión, doble-pick green_state, runTime/runDistance sin parsear) → must-con-banco o post-mundial.

## Agenda semana próxima (detalle en cada issue)
- **Enzo (#106):** mergear #101 → cerrar triage #91 (vence 17) → distribuir #104/#105 → cuidar que Laureano arranque por timeouts.
- **Laureano (#105):** re-aplicar timeouts incremental (PRIORIDAD #1) → T-A get_color → T-B taskDone → #58 break.
- **Benjamin (#104):** #68 pinning → banco/co-review cluster RPi → V-B/V-C performance con medición FPS.
- **Lucio (vía #104):** fixes RPi #65/#66/#73/#64 + V-A/V-D/V-E/V-F, Benjamin valida en banco.

## Alertas / decisiones que Gustavo tiene que firmar
- ✅ **Régimen de fases — DECIDIDO** (gate progresivo 3 fases, ver arriba). Ya no es pregunta abierta.
- Pendiente operativo: el push fuerte real son **3 días** (16→19). Si el triage #91 corre tarde, parte del push F1 se come el fin de semana antes de que entre el gate Enzo el 20.
- TDP/Poster/Video (#95/#97/#98/#94/#96): NO tocan el robot → se pueden trabajar en F2/F3 sin gate de código. Confirmar encuadre con Enzo en el triage.
- Smoke tests PR #100: pendientes, no urgentes (no tocan el robot). OK dejarlos para F2/F3.

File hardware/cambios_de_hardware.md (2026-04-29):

# LED 12V para Sensor de Color (APDS9960)
## Detección de Línea Negra de Salida

---

## 1. EL PROBLEMA

**Situación actual:**
- Robot en fase `evacuacion` espera que la **cámara Raspberry** detecte la línea **negra de salida** 
- La RPi debe procesar detección de víctimas (YOLO) Y detectar línea negra simultáneamente
- Linterna intermitente del torneo + luz ambiental = **variabilidad de luz incontrolable**
- Resultado: Falsos positivos, robot desorientado

**Línea de código crítica (main.cpp, línea 745):**
```cpp
while (rutina == "evacuacion" && digitalRead(32) == 0) {
    serialEvent5();  // Espera comando de cámara
    if(green_state==12) {
        rutina="linea";  // Salida detectada ← depende 100% de RPi
    }
}
```

---
### Opción A — Detección por cámara (método anterior)

La cámara detectaría la línea negra de salida por área de píxeles negros
en la parte inferior del frame, enviando `green_state=12` a la Teensy
por serial cuando el área supera un umbral.

**Por qué falló en la práctica:**

El reglamento 2026 agregó en la sección 3.9 una regla nueva:

> *"The organizers may place white LED lights, mounted perpendicular to
> the wall, on the upper part of the walls."*

Esto significa que hay una **linterna intermitente oficial** dentro de
la zona de evacuación. Cada destello cambia los valores RGB del frame
completo, haciendo que áreas que eran negras pasen a ser grises o
blancas por un frame, y viceversa. El resultado son falsos positivos
constantes: el robot cree que detectó la salida cuando en realidad
era un destello de luz sobre el piso blanco.

Problemas confirmados en pruebas reales:

| Problema | Causa |
|---|---|
| Falso positivo de línea negra | Sombra del robot sobre el piso blanco |
| Falso positivo de línea negra | Destello de linterna sobre objeto oscuro |
| Falso negativo | Linterna ilumina la línea justo cuando el robot pasa |
| Latencia | RPi procesa YOLO + detección de línea simultáneamente → frames perdidos |

## 2. Opción B — LED 12V + APDS9960 (solución elegida)

**Agregar un LED 12V** junto al sensor APDS9960 (ya montado en parte inferior trasera):

```cpp
// Lo que queremos lograr (3 líneas nuevas en loop):
while (rutina == "evacuacion" && digitalRead(32) == 0) {
    digitalWrite(RELAY, HIGH);  // LED enciende (relay ya existe)
    color_detected = get_color();  // ← Leer sensor directamente
    if (color_detected == "Negro") {
        green_state = 12;  // ← Ejecutar accion de salida
        rutina = "linea";
    }
}
```

**Por qué funciona:**
- Sensor en **parte inferior está aislado** de luz ambiente directa
- LED 12V proporciona iluminación **constante y controlada**
- APDS9960 lee reflexión predecible: Negro (C bajo) vs Blanco (C alto)
- **Cero latencia:** Detección en Teensy, no depende de RPi
- **Libera cámara:** RPi enfocada 100% en detección de víctimas (verde/rojo)

En caso de error podemos aplicar varias soluciones con el led de 12V una de ellas es aprovechar el on/off del rele y tambien el IR del sensor  ya que el blanco y plateado en RGB no se van a diferenciar tanto en cambio el blanco en un IR se dispersa en todas las direcciones, el plateado rebota concentradamente como un espejo.

**Solución :** Usar el APDS9960 como **sensor de reflectancia**, no de color:
- **Principal:** Canal C (Clear) = luminancia total
- **Secundario:** readProximity() = sensor IR que mide reflectancia
- **Terciario:** RGB normalizado = solo confirmar que no es color cromático

### Canal C (Clear) — Principal
El canal C es la luminancia total sin filtro de color. Es el indicador más directo de reflectancia:

| Superficie | Canal C |
|---|---|
| Negro | Muy bajo → absorbe casi toda la luz |
| Blanco | Medio-alto → reflexión difusa |
| Plateado | Alto e inestable → reflexión especular |

```cpp
if (c < white_reference_clear * COLOR_BLACK_CLEAR_RATIO) return "Negro";
```

### readProximity() — Secundario
El sensor emite IR y mide cuánto rebota. Aquí aparece la diferencia física entre blanco y plateado:

- **Blanco** → reflexión difusa, el IR se dispersa → PDATA moderado
- **Plateado** → reflexión especular (efecto espejo), el IR rebota concentrado hacia el sensor → PDATA alto

```cpp
if (neutro && c > white_reference_clear * COLOR_SILVER_CLEAR_RATIO
           && p > white_reference_prox  * COLOR_SILVER_PROX_RATIO) return "Plateado";
```

### RGB Normalizado — Terciario
Solo confirma que la superficie no tiene color cromático antes de clasificar 
como blanco o plateado:

```cpp
float rn = (float)r / c;
float gn = (float)g / c;
float bn = (float)b / c;
int delta = max(rn, max(gn, bn)) - min(rn, min(gn, bn));
bool neutro = delta < COLOR_NEUTRAL_SPREAD_MAX;
```

`delta` es la diferencia entre el canal más alto y el más bajo. 
Mide qué tan equilibrados están R, G y B entre sí:

| Superficie | rn / gn / bn | delta | Resultado |
|---|---|---|---|
| Blanco | 0.33 / 0.34 / 0.33 | 0.01 | neutro ✅ |
| Verde | 0.15 / 0.60 / 0.25 | 0.45 | tiene color ❌ |

- `neutro = true` → los tres canales están equilibrados → puede ser blanco o plateado  
- `neutro = false` → algún canal domina → tiene color propio (verde, rojo), se descarta

Solo cuando `neutro == true` se evalúan C y PDATA para decidir entre negro, blanco y plateado

Quedando asi el setup
```cpp
apds.begin(10, APDS9960_AGAIN_1X);  // Ganancia baja (1X)
apds.enableColor(true);
apds.enableProximity(true);         // Habilitar IR
```
Aclaracion la ganancia es muy importante por defecto antes nosotros usabamos el codigo de libreria basico que ponia asi
```cpp
    if (!apds.begin())
    {
        //Serial.println("failed to initialize device! Please check your wiring.");
    }
    else
        //Serial.println("Device initialized!");

    // enable color sensign mode
    apds.enableColor(true);
```
Estabamos pasandole los parametros por defecto que en la libreria nos dicen que son estos 
```cpp

boolean begin(uint16_t iTimeMS = 10, apds9960AGain_t = APDS9960_AGAIN_4X,
              uint8_t addr = APDS9960_ADDRESS, TwoWire *theWire = &Wire);
                              ↑
                    DEFAULT: APDS9960_AGAIN_4X
```

Al tener la ganancia en 4 es como si el sensor reaccionara mucho mas de lo que deberia esto va a fallar mucho en nuestro codigo cuando le implementemos el Led de 12V debido a que puede tomar la reflectancia del blanco y plateado de la misma manera gracias a la ganancia y no habria diferencia

## 4. ESPECIFICACIÓN

**Hardware:**
- LED 12V blanco 
- Conectado a rele existente (ya controlado por la Teensy)
- Ubicación: Junto a sensor APDS9960 en parte inferior 

**Código:**
- Función `get_color()` ya existe 
- APDS9960 ya inicializado 
- Relay ya controlado
- **Agregar:** 3-4 líneas en loop `evacuacion`

---

## 5. PROS Y CONTRAS

**✅ VENTAJAS:**
- Detección autónoma (sin dependencia de cámara)
- Aislada de luz ambiente (ubicación inferior)
- Iluminación controlada (LED 12V constante)
- Código simple (3-4 líneas)
- Hardware existente (relay + sensor ya montado)
- Libera RPi para tareas complejas

**❌ DESVENTAJAS:**
- Soporte 3D requerido para montar el LED
- Soldado o conexionado adicional

Esta es en mi opinion otra mejora prioritaria aunque requiere agregar un soporte 3D y montar un LED adicional, el beneficio en confiabilidad justifica completamente el cambio.La utilidad principal es asegurar una salida consistente de evacuación sin depender de condiciones externas imposibles de controlar.
# ESP32 Super Mini — Implementación SuperTeam Challenge

## 1. EL PROBLEMA

El reglamento 2026 indica en la sección 6.3:

> *"It is highly recommended that teams bring some kind of communication hardware
or think about a communication mechanism for this challenge."*

El robot actualmente **no tiene ningún mecanismo de comunicación** entre equipos.
Para el SuperTeam Challenge se necesita coordinar acciones entre dos robots de equipos distintos en tiempo real.

## 2. LA SOLUCIÓN

**Agregar una ESP32 Super Mini** conectada a la Teensy vía Serial8 (pines 34/35):

```cpp
// Comunicación Teensy ↔ ESP32
// Serial8 RX → pin 34  (antes: BUZZER)
// Serial8 TX → pin 35  (antes: LED_ROJO)
```

La ESP32 actúa como módulo BLE dedicado: recibe comandos de la Teensy por serial y los transmite al robot del otro equipo, y viceversa.

**Por qué ESP32 Super Mini:**
- Tamaño reducido → cabe en espacio limitado dentro del robot
- BLE nativo → sin hardware adicional para comunicación
- MicroPython ya conocido por el equipo → curva de aprendizaje mínima
- Bajo consumo → no impacta la alimentación del robot
## 3. CAMBIOS REQUERIDOS

### Software —  (2 líneas)
Todo el código usa los defines `BUZZER` y `LED_ROJO`, nunca los números de pin 
directamente. El compilador resuelve el resto solo:

```cpp
// Antes
#define BUZZER   35
#define LED_ROJO 34

// Después
#define BUZZER   31
#define LED_ROJO 30
```

### Hardware — 

| Tarea | Detalle |
|---|---|
| Desconectar BUZZER | desoldar cable del pin 35, reconectar al pin 31 |
| Desconectar LED_ROJO | desoldar cable del pin 34, reconectar al pin 30 |
| Conectar ESP32 | Pin 34 (RX8) y pin 35 (TX8) de la Teensy → UART de la ESP32 |
| Soporte 3D | Diseñar e imprimir soporte interno para montar la ESP32 |

Esto implica **desarmar el robot**, soldar cables y volver a armarlo.

---

### Alimentación
La ESP32 Super Mini se alimenta directamente desde el regulador de 5V del robot:

- **VIN de la ESP32** → 5V del regulador existente
- **GND** → GND común del robot

Sin componentes adicionales, sin regulador extra.

## 5. PROS Y CONTRAS

**✅ VENTAJAS:**
- Cumple el requerimiento de comunicación del SuperTeam Challenge
- Tamaño compacto (ESP32 Super Mini)
- MicroPython ya conocido por el equipo
- BLE integrado, sin módulos externos adicionales
- Cambio de código mínimo (solo 2 líneas)

**❌ DESVENTAJAS:**
- Requiere desarmar el robot para reconectar BUZZER y LED_ROJO
- Espacio interno limitado → requiere diseño 3D eficiente para el soporte

Asi quedaria el esquematico con la implementacion de la ESP32 para el superTeam

descargar (1)-1

## 4. ANÁLISIS COMPARATIVO DE OPCIONES

Antes de elegir la ESP32 Super Mini se evaluaron otras opciones:

### HC-05 — Análisis detallado

#### Especificaciones técnicas
| Parámetro | Valor |
|---|---|
| Bluetooth | v2.0 + EDR |
| Frecuencia | 2.4 GHz ISM |
| Rango | hasta 100m |
| Baud rate data mode | 9600 bps por defecto |
| Baud rate AT mode | 38400 bps |
| Pines | 6 (EN, VCC, GND, TX, RX, STATE) |
| Roles | Maestro o Esclavo (configurable) |

#### Modos de operación

**Data Mode** (por defecto al encender):
- El módulo actúa como puente serial transparente
- Todo lo que entra por TX sale por Bluetooth y viceversa

**AT Command Mode** (para configurar):
- Se activa manteniendo el pin EN/KEY en HIGH al encender
- LED: parpadeo lento (~1 vez por segundo)
- Baud rate en este modo: 38400 bps
#### Proceso de configuración maestro-esclavo

Para conectar dos HC-05 entre dos robots se necesita hacer esto
**antes** del challenge:

**Paso 1 — Configurar el esclavo:**
- AT+ROLE=0          → modo esclavo
- AT+NAME=ROBOT_B    → nombre identificable
- AT+PSWD=1234       → contraseña
- AT+UART=115200,0,0 → baud rate
- AT+ADDR?           → obtener la MAC address del esclavo (formato: 1234:56:ABCDEF)

**Paso 2 — Configurar el maestro:**
AT+ROLE=1                    → modo maestro
AT+CMODE=0                   → conectar a dirección fija
AT+BIND=1234,56,ABCDEF       → MAC del esclavo (: reemplazado por ,)
AT+UART=115200,0,0           → mismo baud rate que esclavo

**Paso 3 — Verificar:**
- Apagar ambos módulos
- Encender primero el esclavo, luego el maestro
- El maestro busca y conecta automáticamente al esclavo
- Ambos LEDs pasan a doble parpadeo = conectados

#### El problema crítico para el SuperTeam Challenge

El proceso anterior tiene un supuesto fatal: **necesitás tener físicamente
el módulo del otro equipo para obtener su MAC address antes del challenge.**

En la competencia esto no es posible porque:
- Los equipos se asignan al momento del challenge
- No hay tiempo de configuración entre equipos
- Si el otro equipo trae HC-06 (solo esclavo), es imposible conectar
  dos HC-06 entre sí ya que ambos esperan que el otro inicie la conexión
- Si el otro equipo trae HC-05 pero con distinta versión de firmware,
  algunos comandos AT pueden no funcionar igual

Existe `AT+CMODE=1` que conecta al primer dispositivo disponible sin
necesitar la MAC, pero en una sala de torneo con múltiples equipos con
Bluetooth encendido, el maestro puede conectarse al robot equivocado.

#### Problema adicional: roles fijos durante la ejecución

En el SuperTeam Challenge la comunicación no es unidireccional.
Dependiendo de la tarea, un robot puede necesitar:
- **enviar** una señal al otro ("llegué al checkpoint")
- **recibir** una orden del otro ("esperame antes de continuar")

Con HC-05 los roles maestro y esclavo son **fijos en hardware**:
no se pueden intercambiar en tiempo de ejecución sin entrar al modo AT,
enviar comandos y reiniciar el módulo. Esto hace imposible que ambos
robots reaccionen dinámicamente según la situación.

Con la ESP32 en BLE, ambos robots pueden **transmitir y recibir
simultáneamente** sin cambiar de rol, ya que el broadcast es
independiente de quién inició la conexión.

### HC-06

- **Solo esclavo** — no puede iniciar conexiones, solo espera que otro
  dispositivo se conecte
- Dos HC-06 **no pueden comunicarse entre sí** bajo ninguna circunstancia
- Comandos AT muy limitados: solo permite cambiar nombre, baud rate y PIN
- Los comandos AT deben enviarse en menos de 1 segundo o el módulo no
  los reconoce
- **Descartado:** no sirve para robot-a-robot sin saber qué trae el otro equipo
### Por qué el broadcast de BLE es la clave

Con HC-05 o HC-06 la comunicación es como una llamada telefónica:
necesitás saber el número del otro antes de llamar, y solo uno puede
llamar mientras el otro espera. Con el BLE broadcast de la ESP32 es
como una radio: cualquiera transmite cuando necesita y cualquiera que
esté escuchando recibe, sin importar quién es el otro equipo ni qué
hardware trae.

Dado que el SuperTeam Challenge asigna equipos al momento de la
competencia, el broadcast elimina completamente la dependencia del
hardware del otro equipo y permite comunicación bidireccional dinámica.

Considero que la incorporación de una ESP32 Super Mini es una de las soluciones prioritarias ya que resuelve directamente el problema real de comunicación entre robots sin depender del hardware del otro equipo.
Las opciones como HC-05 o HC-06 presentan demasiadas limitaciones prácticas para una competencia donde los equipos se asignan en el momento. Tener que conocer previamente la MAC address del otro robot o depender de roles maestro/esclavo fijos introduce un riesgo innecesario que puede hacer fallar toda la prueba incluso antes de comenzar Aunque es necesario desarmar al robot para incorporar la mejora el beneficio para mi es mucho mayor

# Finales de Carrera — Mejora de Alineación y Retroceso

---

## 1. EL PROBLEMA

En la fase de rescate y evacuación el robot necesita:

**A) Alinearse contra la pared para depositar víctimas:**
```cpp
runAngle(20, FORWARD, 180);
runTime(10, BACKWARD, 0, 2000);  // ← retrocede por tiempo fijo
```
El problema es que retroceder por tiempo no garantiza la misma
distancia final. Según la distancia donde recogio su ultima victima el robot 
puede quedar más cerca o más lejos de la pared, lo que afecta
directamente la precisión del depósito. En caso de que nos quedemos corto de distancia nosotros aumentabamos los milisegundo de retroceso y con eso bastaba 

**B) Saber cuándo el robot está bien alineado:**
Actualmente se usa el BNO055 para girar 180° y retroceder, pero
el ángulo no garantiza que ambos lados del robot estén a la misma
distancia de la pared. Si el robot queda levemente torcido es perjudicial cuando navegamos a ciegas con los 3 ultrasonidos

---

## 2. OPCIONES EVALUADAS

### Opción A — Usar pitch del BNO055 (sin cambio de hardware)

El BNO055 ya tiene la función `leer_pitch()` implementada:

```cpp
void leer_pitch()
{
    sensors_event_t event;
    bno.getEvent(&event);
    pitch = event.orientation.y;
}
```

Y ya se usa para ajustar velocidad en rampas:

```cpp
int ajustarVelocidadPorPendiente(int velocidadBase)
{
    leer_pitch();
    if (pitch > 10) return 30;
    else return 25;
}
```

La idea sería: en vez de retroceder por tiempo fijo, retroceder
hasta que el pitch supere un umbral, indicando que el robot
comenzó a levantarse contra la pared.

```cpp
// Concepto
while (digitalRead(32) == 0) {
    leer_pitch();
    robot.steer(10, BACKWARD, 0);
    if (abs(pitch) > PITCH_WALL_THRESHOLD) break;
}
```

**Pros:**
- ✅ Sin cambio de hardware
- ✅ Sin desarmar el robot
- ✅ Sin diseño 3D adicional
- ✅ Sensor ya presente y funcionando

**Contras:**
- ❌ Menos preciso: el pitch varía según el peso de la garra y la carga
- ❌ El umbral cambia si hay pelotitas vs sin pelotitas
- ❌ No detecta alineación lateral: el robot puede estar torcido
  y aun así el pitch subir igual
- ❌ Se pierden segundos esperando que el pitch alcance el umbral
- ❌ En superficies irregulares como las lomas de burros el pitch puede dar falsos positivos

---

### Opción B — Finales de carrera (solución elegida)

Dos finales de carrera montados en la parte trasera del robot,
uno en cada extremo. Conectados a los **2 pines digitales libres**
que quedan disponibles en caso de la aprobacion de la ESP32 Super Mini.

#### Principio de funcionamiento

Cuando el robot retrocede contra la pared:

- Si **solo uno** se activa → el robot está torcido → seguir corrigiendo
- Si **los dos** se activan simultáneamente → el robot está alineado → frenar

```cpp
#define FC_IZQUIERDO 41   // pin digital libre
#define FC_DERECHO   40   // pin digital libre

// Retroceso con alineación por finales de carrera
while (digitalRead(32) == 0) {
    robot.steer(10, BACKWARD, 0);
    bool fc_izq = digitalRead(FC_IZQUIERDO) == LOW;
    bool fc_der = digitalRead(FC_DERECHO)   == LOW;
    if (fc_izq && fc_der) break;  // alineado → frenar
}
robot.steer(0, FORWARD, 0);
```

#### Aplicación en depósito de víctimas

Reemplaza el `runTime(10, BACKWARD, 0, 2000)` por retroceso
controlado:

```cpp
if (green_state == 8) // rojo
{
    digitalWrite(RELAY, HIGH);
    runAngle(20, FORWARD, 180);

    // Antes: runTime(10, BACKWARD, 0, 2000);  ← tiempo fijo
    // Ahora: retroceder hasta que ambos FC choquen
    while (digitalRead(32) == 0) {
        robot.steer(10, BACKWARD, 0);
        if (digitalRead(FC_IZQUIERDO) == LOW &&
            digitalRead(FC_DERECHO)   == LOW) break;
    }
    robot.steer(0, FORWARD, 0);

    claw.depositLeft();
    delay(2000);
    claw.depositCenter();
    runTime(0,  FORWARD, 0, 500);
    runTime(30, BACKWARD, 0, 500);
    runTime(0,  FORWARD, 0, 500);
    runDistance(30, FORWARD, 40);
    veces_deposit++;
}
```

Una vez que los dos finales de carrera chocaron simultáneamente
contra la pared, el robot está alineado y la garra queda siempre
a la misma distancia y ángulo del triángulo de depósito.
No hay riesgo de que las víctimas se caigan porque el robot
ya está contra la pared y no se mueve más hacia atrás.

**Pros:**
- ✅ Detección física directa: si los dos tocaron, estamos alineados
- ✅ Sin falsos positivos por superficie irregular
- ✅ Mismo pin digital de lectura simple (`digitalRead`)
- ✅ Usa los 2 pines libres disponibles tras la ESP32

**Contras:**
- ❌ Requiere desarmar el robot para el cableado
- ❌ Requiere diseño e impresión 3D de soportes para los finales

## PROS Y CONTRAS FINALES

**✅ VENTAJAS:**
- Alineación física garantizada contra la pared
- Depósito siempre a la misma distancia y ángulo
- Sin dependencia de sensores de orientación
- Aprovecha los pines liberados por la ESP32 Super Mini

**❌ DESVENTAJAS:**
- Requiere desarmar el robot
- Soporte 3D debe ser preciso y simétrico
- Cableado adicional interno

# Detección de Víctimas Plateadas Falsas — Pin de Conductividad
 
---
 
## 1. EL PROBLEMA
 
El reglamento 2026 indica en la sección 3.10:
 
> *"The organizers may place fake victims (objects or images) that
> resemble real victims in the evacuation zone. Robots should ignore them."*
 
Y en la sección 3.10.3:
> *"Living victims are silver, reflect light, and are electrically conductive."*
> *"Dead victims are black and not electrically conductive."*
 
Las víctimas plateadas falsas son visualmente idénticas a las reales
para la cámara. El modelo YOLO las clasificará como `plateado` igual
que a las verdaderas, enviando `green_state=7` a la Teensy.
 
**El problema:** el robot ejecuta toda la secuencia de recolección,
gasta tiempo, y deposita una víctima falsa que no suma puntos.
 
---
 
## 2. LA SOLUCIÓN
 
Dos cables conectados a la garra: uno a un pin digital de la Teensy
con `INPUT_PULLUP` y otro a GND. Cuando la garra cierra sobre
una víctima, los cables hacen contacto con su superficie.
 
- **Víctima plateada real** → conductiva → cierra el circuito → pin lee `LOW`
- **Víctima plateada falsa** → no conductiva → circuito abierto → pin lee `HIGH`

```cpp
#define CONDUCTIVIDAD 26  // único pin libre disponible
 
pinMode(CONDUCTIVIDAD, INPUT_PULLUP);
 
// Dentro de green_state == 7, después de claw.close():
if (green_state == 7) {
    digitalWrite(RELAY, HIGH);
    runTime(0, FORWARD, 0, 1000);
    claw.lower();
    claw.sortLeft();
    delay(1000);
    claw.depositCenter();
    delay(1000);
    runDistance(20, FORWARD, 7);
    runTime(0, FORWARD, 0, 1000);
    claw.close();
    delay(500);
 
    // Verificar conductividad
    if (digitalRead(CONDUCTIVIDAD) == LOW) {
        // Es real → continuar recolección normal
        digitalWrite(BUZZER, HIGH);
        delay(100);
        digitalWrite(BUZZER, LOW);
        runTime(0, FORWARD, 0, 1000);
        claw.lift();
        delay(1000);
        claw.open();
        delay(1000);
        runTime(30, FORWARD, 0, 200);
        runTime(30, BACKWARD, 0, 200);
        ball_counter++;
    } else {
        // Es falsa → soltar inmediatamente
        claw.open();
        delay(500);
        runTime(30, BACKWARD, 0, 300);
    }
}
```
 
---
 
## 3. EL PROBLEMA DEL CABLE
 
La solución es simple en electrónica pero el punto crítico
es el cable físico que va desde la Teensy hasta la garra.
 
La garra realiza este ciclo constantemente:
 
```
lower() → close() → lift() → open() → depositCenter() → lower() → ...
```
 
Esto significa que el cable sube y baja con cada recolección,
queda tensado en la posición alta, se dobla repetidamente en
el mismo punto y está expuesto a tirones cuando la garra
cierra sobre una víctima.
 
**Un cable UTP estándar fallaría porque:**
- Conductor de cobre sólido → se quiebra en pocas flexiones repetidas
- Aislante rígido → se agrieta y expone el conductor
- Sin margen de longitud → tirón directo en cada movimiento extremo
### Cable recomendado — disponible en Mercado Libre Argentina
 
| Tipo | Por qué sirve | Disponible en MercadoLibre |
|---|---|---|
| **Jumper** | Conductor multifilar, aislante tipo goma, diseñado para movimiento en robótica Arduino | ✅ Sí, múltiples vendedores |
| **Cable siliconado AWG 28** | Aislante de silicona ultra flexible, conductor cobre estañado trenzado 16 hilos, soporta flexión continua | ✅ Sí |
| **Cable multifilar flexible** | Conductor multifilar genérico, más económico | ✅ Sí |
 
La opción más práctica es el **Jumper** porque:
- Ya viene con el conductor multifilar que distribuye el estrés de flexión
- El aislante tipo goma no se agrieta con el movimiento repetitivo
- Se consigue fácilmente en cualquier tienda de electrónica o Mercado Libre
- No requiere crimpado ni procesado especial
### Consideraciones de montaje
 
- Dejar **holgura suficiente** en la posición más extendida de la garra
  para que nunca quede tensado
- Fijar el cable al brazo con una pequeña lazada para que el movimiento
  se distribuya a lo largo del cable y no se concentre en un punto
- El punto de soldadura al electrodo de la garra debe tener
  **alivio de tensión**: un punto de fijación a pocos mm de la soldadura
  para que el tirón no caiga directo sobre el estaño
---
 
## 4. ESPECIFICACIÓN
 
**Hardware:**
- 2 cables Dupont flexibles (o siliconados AWG 28)
- Pin Teensy: **26** con `INPUT_PULLUP`
- GND: GND común del robot
- Puntos de contacto en la garra: dos electrodos separados
  que toquen la superficie de la víctima al cerrar
**Código:**
- `pinMode(CONDUCTIVIDAD, INPUT_PULLUP)`
- `digitalRead(CONDUCTIVIDAD) == LOW` → víctima real → continuar
- `digitalRead(CONDUCTIVIDAD) == HIGH` → víctima falsa → soltar
---
 
## 5. PROS Y CONTRAS
 
**✅ VENTAJAS:**
- Solución electrónicamente muy simple (un pin, dos cables)
- Usa el único pin libre disponible (pin 26)
- Sin carga computacional adicional
- Detección instantánea: un solo `digitalRead`
- `INPUT_PULLUP` interno evita ruido sin resistencia externa
- Ahorra tiempo al soltar falsas inmediatamente
- Cable Jumper disponible en Mercado Libre Argentina

**❌ DESVENTAJAS:**
- Cable expuesto a fatiga mecánica por movimiento repetitivo
  → requiere cable flexible especial (no cable UTP estándar)
- El montaje de los cables en la garra debe asegurar
  contacto confiable con la víctima al cerrar
- Si el cable se rompe durante la competencia, se pierde
  la detección pero el robot no falla completamente

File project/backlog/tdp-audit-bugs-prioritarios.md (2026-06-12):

# Auditoria del TDP en rama Bugs-Prioritarios

Fecha: 2026-05-22
Archivo revisado: `TDP.md`
Rama local: `Bugs-Prioritarios`
Repo: `IITA-Proyectos/rcj-2026-rescue-line-iita-salta-robocup`

## Diagnostico corto

El TDP actual ya tiene bastante texto, pero todavia no esta en condicion de puntaje alto. El problema principal no es "falta escribir mas"; es que el documento:

- no usa la ubicacion/estructura pedida en los issues (`docs/tdp/TDP-IITA-2026.md`);
- no sigue de forma estricta la plantilla oficial 2026;
- promete pruebas, metricas, diagramas y fotos que no estan citadas o no existen en la rama local;
- mezcla texto generico con afirmaciones fuertes no demostradas;
- tiene errores de Markdown que rompen secciones completas;
- no cruza cada componente contra requirements derivados de reglas RCJ 2026;
- no incorpora los avances ya mergeados en `origin/main`, especialmente `testing/TEST_LOG.md`.

Estimacion honesta: si el juez acepta texto declarativo sin mucha evidencia, podria estar cerca de 20-30/102. Si el juez es estricto con plantilla, diagramas, evidencia y trazabilidad, puede caer a 10-18/102. Para llegar a 80-100 hay que convertirlo en un paquete con evidencias, no solo en un texto largo.

## Issues de GitHub relevantes

| Issue/PR | Estado detectado | Impacto sobre el TDP |
|---|---:|---|
| #46 Armado de TDP | Abierto | Issue padre del TDP. Pide estructura por rubrica, carpeta `docs/tdp/`, template oficial y PDF final. |
| #97 META Documentacion pre-mundial | Abierto | Define meta: TDP 102 pts, actual estimado bajo, potencial 80-90. |
| #98 Plan de ejecucion para 100% | Abierto | Lista tareas T1-T17 para TDP y dependencias. |
| #41 Diagramas de bloques o flujo | Abierto | Bloquea T12 Software architecture diagrams y tambien Poster. |
| #93 Inicializar `testing/TEST_LOG.md` | Cerrado | PR #101 lo mergeo en `main`, pero esta rama local todavia no lo tiene. |
| PR #101 `testing/TEST_LOG.md` | Mergeado 2026-05-19 | Crea template de test log, pero no trae tests historicos reales. Hay que mergear/rebasear o copiarlo. |
| #95 Validar fidelidad tecnica | Abierto | Antes de copiar docs/es al TDP, verificar que no digan bugs ya arreglados. |
| #96 BOM actualizado | Abierto | Bloquea electronica: BOM oficial, componentes, costos, links, funcion. |

## Hallazgos locales importantes

- `TDP.md` esta sin trackear en la rama local.
- `software/teensy/firmware/variables_doc.md` contiene el mismo contenido que `TDP.md` o parece haber sido usado como copia. Eso es un error fuerte: un TDP no debe vivir dentro de firmware ni llamarse `variables_doc.md`.
- La rama local esta 1 commit adelante y 17 commits atras de `origin/main`.
- En la rama local `testing/` tiene solo `.gitkeep`, aunque en `origin/main` ya existen `testing/README.md` y `testing/TEST_LOG.md`.
- `origin/main` tiene `docs/es/analisis-documentacion-rubricas-2026-05-10.md`, que esta rama local no tiene.

## Errores criticos del TDP actual

### 1. Ubicacion y nombre del archivo

Error: el archivo esta como `TDP.md` en la raiz y no como `docs/tdp/TDP-IITA-2026.md`, que es lo pedido por #46 y #98.

Arreglo:

1. Crear `docs/tdp/`.
2. Mover el documento a `docs/tdp/TDP-IITA-2026.md`.
3. Mantener `TDP.md` raiz solo si se usa como redirect/indice, o eliminarlo cuando haya PR.

### 2. No esta basado fielmente en la plantilla oficial 2026

Error: la rubrica oficial 2026 evalua 17 items T1-T17. El TDP usa secciones parecidas, pero no demuestra cada criterio con claridad.

Arreglo:

- Descargar/usar `TDP_Template_Line_Maze.docx`.
- Crear headings que mapeen 1:1 contra T1-T17.
- Antes de cada seccion, decidir que evidencia la sostiene.

### 3. Project Planning: faltan requirements reales

Lineas relevantes: `TDP.md:34`, `TDP.md:42`, `TDP.md:204`.

Error: hay objetivos generales, timeline y success criteria, pero no una lista de requirements derivados de reglas RCJ 2026. Ejemplos que faltan: dimensiones, peso si aplica, rampas, seesaw, victimas, zona de evacuacion, obstaculos, limites de intervencion humana, comunicacion, energia, seguridad.

Arreglo:

- Crear tabla: `Requirement`, `Regla/criterio`, `Decision de diseño`, `Modulo que lo cumple`, `Evidencia`.
- Citar reglas oficiales 2026.

### 4. Plan de proyecto demasiado declarativo

Lineas: `TDP.md:61`, `TDP.md:204`, `TDP.md:221`.

Error: las responsabilidades son por rol, pero el milestone schedule no asigna owner real ni evidencia de completion. Los gates existen como texto, no como proceso verificable.

Arreglo:

- Tabla con owner por milestone.
- Link a issue/PR/test/foto/video que demuestre cada hito.
- Incluir cambios historicos reales, no solo fechas deseadas.

### 5. Integration Plan incompleto

Lineas: `TDP.md:859`, `TDP.md:875`, `TDP.md:925`.

Error: hay diagramas parciales, pero no hay matriz `componente -> requirement -> comunicacion -> evidencia`. La rubrica pide claridad sobre conexiones y que requirements cumple cada parte.

Arreglo:

- Diagrama de sistema completo.
- Tabla por componente: RPi, Teensy, PCB, motores, encoders, camara, BNO055, APDS9960, ToF, ultrasonicos, servos, bateria.

### 6. Seccion mecanica sin imagenes reales ni CAD referenciado

Lineas: `TDP.md:330` a `TDP.md:577`.

Error: describe muy bien muchas piezas, pero no muestra fotos ortogonales, CAD, medidas, renders, materiales con parametros de impresion ni ubicacion de sensores.

Arreglo:

- Agregar fotos top/front/side/rear.
- Agregar captura CAD con labels.
- Agregar dimensiones y material de cada modulo.
- Linkear STL/CAD/revision si existen.

### 7. Bloque Markdown roto en mecanica

Lineas: `TDP.md:581` a `TDP.md:640`.

Error: se abre un bloque ```text en `Mechanical Module Interaction Diagram` y no se cierra antes de `##2.3`. Eso hace que gran parte de la seccion quede renderizada como codigo.

Arreglo:

- Cerrar el bloque antes de "Main Mechanical Interfaces".
- Convertir interfaces, quick access features y serviceability a headings/listas normales.

### 8. Headings mal formateados

Lineas: `TDP.md:640`, `TDP.md:679`, `TDP.md:791`.

Error: headings como `##2.3`, `##2.4`, `##2.5` no tienen espacio. Algunos renderizadores no los reconocen como headings.

Arreglo:

- Cambiar a `## 2.3`, `## 2.4`, `## 2.5`.

### 9. Tests mecanicos declarados sin evidencia

Lineas: `TDP.md:679` a `TDP.md:789`.

Error: afirma `More than 300 pickup cycles`, `>95%`, `100%`, etc. sin fecha, tester, setup, numero de corridas, evidencia, video, log ni metodo de medicion.

Arreglo:

- Todo numero debe apuntar a `testing/TEST_LOG.md`.
- Si no existe evidencia, cambiar a "planned validation" o reconstruir el test honestamente.

### 10. Electronica con placeholders

Lineas: `TDP.md:813`, `TDP.md:815`.

Error original: quedaban `[Insert Figure 3]` y `[Insert Figure 4]`. Esto destruia T8/T17.

Estado 2026-05-23: resuelto en el nuevo `TDP.md` con `hardware-overview-2026.png`, `pcb-main-layout-2026.png` y `electronics-schematic-2026.png` en `docs/tdp/assets/`.

Arreglo:

- Reemplazar por fotos/diagramas reales: PCB photo, wiring layout, schematic, power tree.

### 11. Power system insuficiente

Lineas: `TDP.md:831` a `TDP.md:835`.

Error: menciona bateria y regulador, pero faltan corriente maxima, protecciones, fusible/switch, reguladores por rail, consumo RPi/servos/motores, ruido, caidas de tension, conectorado.

Arreglo:

- Agregar power tree: bateria -> switch -> rail motores -> buck 5V -> RPi/logic -> servos/sensores.
- Agregar mediciones de voltaje bajo carga.

### 12. Comunicacion serial incompleta

Lineas: `TDP.md:837` a `TDP.md:846`, `TDP.md:992`.

Error: el protocolo aparece como bytes sueltos. Falta frame completo, direccion, frecuencia, checksum/delimiters si existen, timeout, comportamiento ante perdida de comunicacion.

Arreglo:

- Dibujar sequence diagram RPi -> Teensy.
- Documentar frame exacto desde el codigo actual.
- Agregar errores conocidos y fixes.

### 13. BOM no integrado

Issue: #96.

Error: el TDP lista componentes principales, pero no tiene BOM oficial ni link a archivo actualizado.

Arreglo:

- Crear `hardware/electronics/BOM-2026.xlsx` o tabla Markdown equivalente.
- Incluir modelo, cantidad, proveedor, link, precio, funcion, reemplazo.

### 14. Software architecture no alcanza para T12

Lineas: `TDP.md:889` a `TDP.md:1004`.

Error: hay ASCII diagram y state machine, pero falta:

- flowchart real del main loop Teensy;
- flowchart real de `Main.py`;
- diagrama de comunicacion serial;
- state machine de pinza/rescate;
- class/module diagram;
- pseudocodigo de algoritmos criticos.

Arreglo: ejecutar issue #41 y guardar fuente + PNG/SVG en `docs/diagrams/`.

### 15. Secciones de software demasiado genericas

Lineas: `TDP.md:1006` a `TDP.md:1057`.

Error: frases como "hybrid pipeline", "adaptive line-following", "sensor fusion", "fault-tolerant recovery" suenan bien, pero no explican algoritmo, parametros, casos borde, ni ventaja medida.

Arreglo:

- Para cada algoritmo: input, output, pseudocodigo, parametros, caso borde, evidencia.

### 16. Tests de software sin pruebas reales

Lineas: `TDP.md:1059` a `TDP.md:1133`.

Error: enumera unit/integration/stress/robustness tests, pero no hay archivos de tests, comandos, logs, videos ni resultados reales.

Arreglo:

- Vincular a `testing/TEST_LOG.md`.
- Agregar comandos reproducibles si hay tests automatizados.
- Si no hay tests unitarios, no llamarlos "unit tests"; llamarlos "manual module validation" hasta que existan.

### 17. Performance Evaluation sin metodologia

Lineas: `TDP.md:1149` a `TDP.md:1228`.

Error: muestra numeros aproximados (`10 cm/s`, `14-20 FPS`, `90 min`, etc.) sin explicar como se midieron.

Arreglo:

- Para cada metrica: fecha, setup, cantidad de corridas, promedio, desviacion/rango, resultado, link a evidencia.
- Separar "observado informalmente" de "medido".

### 18. Overclaiming: promete puntaje alto sin demostrarlo

Lineas: `TDP.md:1146`, `TDP.md:1272`.

Error: "satisfy the highest evaluation criteria" es riesgoso. Un juez espera evidencia; si ve placeholders y no ve logs, esa frase resta credibilidad.

Arreglo:

- Cambiar tono a factual: "The design addresses the criteria through..." y linkear evidencia.

### 19. Seccion Document se autoevalua en lugar de mejorar

Lineas: `TDP.md:1231` a `TDP.md:1266`.

Error: la seccion dice que el documento es claro/formateado, pero todavia contiene placeholders, headings rotos y seccion 6.3 faltante.

Arreglo:

- Usar esa seccion solo si la plantilla oficial la pide.
- Completar `6.3` o renumerar.
- Eliminar "figure placeholders" de la lista de formatting; placeholders no son virtud.

### 20. Extra content final poco profesional

Lineas: `TDP.md:1286` a `TDP.md:1296`.

Error: `## . extra content`, links sueltos y "Thank you for reading" quedan informales para entrega.

Arreglo:

- Reemplazar por `References` / `Links`.
- Incluir links con descripcion y fecha de consulta si corresponde.

## Prioridad de trabajo recomendada

### Bloque 0: sincronizar base

1. Traer a la rama los 17 commits que faltan de `origin/main` o cherry-pick de PR #101 si no quieren mezclar todo.
2. Recuperar `testing/README.md`, `testing/TEST_LOG.md` y `docs/es/analisis-documentacion-rubricas-2026-05-10.md`.
3. Revisar conflictos con `software/teensy/firmware/variables_doc.md` y decidir si debe borrarse o restaurarse a su proposito real.

### Bloque 1: ganar puntos rapidos

1. Crear `docs/tdp/TDP-IITA-2026.md`.
2. Arreglar Markdown roto y headings.
3. Eliminar placeholders.
4. Crear indice T1-T17.
5. Agregar links a evidencias ya existentes.

### Bloque 2: evidencias

1. Llenar `testing/TEST_LOG.md` con 5-10 tests reales.
2. Sacar fotos del robot y PCB.
3. Crear diagramas de #41.
4. Crear BOM de #96.
5. Validar fidelidad tecnica de #95.

### Bloque 3: convertir texto generico en puntaje

Para cada seccion:

- escribir que hicieron;
- mostrar diagrama/foto;
- explicar por que esa decision resuelve un requirement;
- demostrar con test/log/video;
- cerrar con limitacion honesta y mejora futura.

## Checklist T1-T17 contra archivo actual

| Tema | Rubrica | Estado actual | Accion |
|---|---|---|---|
| T1 | Requirements | Debil | Lista desde reglas 2026 + matriz requirement/componente. |
| T2 | Project plan | Medio | Agregar owners, issues, PRs, gates reales. |
| T3 | Integration | Debil | Diagrama formal + matriz de interfaces. |
| T4 | Mechanical diagrams | Debil | Fotos/CAD/medidas. |
| T5 | Mechanical submodules | Medio-bajo | Cerrar bloque roto + diagramas de interfaces. |
| T6 | Mechanical innovation | Medio | Foto/sketch/ventaja medible. |
| T7 | Mechanical tests | Debil | TEST_LOG con ciclos reales, setup y evidencia. |
| T8 | Electronic diagrams | Muy debil | Reemplazar placeholders por schematic/PCB/power tree. |
| T9 | Electronic submodules | Medio-bajo | Power tree + wiring + funciones por modulo. |
| T10 | Electronic innovation | Debil | Probar PCB propia con BOM/esquematico/fotos. |
| T11 | Electronic tests | Debil | Voltage/current/noise tests. |
| T12 | Software diagrams | Medio-bajo | Ejecutar #41 completo. |
| T13 | Software innovation | Medio | Pseudocodigo + ventaja medida. |
| T14 | Software tests | Debil | Tests manuales/automatizados reales, no lista declarativa. |
| T15 | Performance | Debil | Metricas con metodo, corridas y conclusion. |
| T16 | Clarity | Medio-bajo | Quitar repeticion, corregir estructura, tono factual. |
| T17 | Formatting | Muy debil | Template oficial + PDF final + placeholders fuera. |

## Regla de oro para no inventar puntaje

Cada numero del TDP debe tener una fuente:

- un test en `testing/TEST_LOG.md`;
- un video/foto;
- un commit/PR;
- una medicion reproducible;
- un documento tecnico en `docs/es` validado contra codigo actual.

Si no tiene fuente, no se borra necesariamente, pero se marca como objetivo, estimacion o observacion preliminar.

## Segunda pasada: cobertura de issues para objetivo 102/102

Estado honesto de lectura:

- Primera pasada: busqueda por TDP/rubrica/documentacion. Cubrio #41, #45, #46, #55, #93, #94, #95, #96, #97, #98 y PR #101.
- Segunda pasada: se reviso tambien el triage de #91, que enumera los 31 issues tecnicos abiertos, y los meta-issues recientes #102, #106, #114, #118, #120-#128.
- No alcanza con "issues sobre TDP" literales: para sacar 100%, el TDP tiene que demostrar un robot confiable con evidencias. Por eso entran tambien issues de bugs, testing y performance.

### Issues que son bloqueantes directos del 100% del TDP

| Issue | Por que bloquea puntaje TDP | Seccion TDP afectada |
|---|---|---|
| #46 | Issue padre. Pide archivo Markdown en docs, estructura por rubrica, template oficial y PDF. | T16, T17, todo el documento |
| #97 | Define roadmap de documentacion pre-mundial y puntaje actual/potencial. | Todas |
| #98 | Plan de ejecucion para TDP 102/102 con T1-T17. | Todas |
| #41 | Faltan flowcharts, comunicacion, FSM y pseudocodigo. | T12, tambien T3 |
| #93 / PR #101 | TEST_LOG existe en main pero esta rama no lo tiene; ademas esta vacio de tests reales. | T7, T11, T14, T15 |
| #94 | Fotos de equipo/robot. Aunque es poster/video, tambien sube T4/T8/T16 del TDP. | T4, T8, T16 |
| #95 | Evita copiar docs obsoletas al TDP. | T16, T15, credibilidad general |
| #96 | BOM actualizado. Sin BOM no se defiende electronica al maximo. | T8, T9, T10 |
| #45 | Poster comparte fotos, datos y diagramas con TDP. | Insumo visual |
| #55 | Video comparte evidencia de robot en accion. | T15, evidencia |

### Issues tecnicos que el TDP debe citar como evidencia o como riesgo resuelto

Estos no son "del TDP" por titulo, pero si el TDP quiere 100%, debe demostrar que el equipo identifico, corrigio o valido estos puntos. Si siguen abiertos, el TDP debe tratarlos como riesgos controlados con plan/test.

| Grupo | Issues | Impacto sobre el documento |
|---|---|---|
| Fail-safe / watchdog / timeouts | #27, #53, #59, #60, #61, #62, #63, #72, #73 | T14/T15: confiabilidad del software y comportamiento ante fallas. |
| Comunicacion RPi-Teensy | #70, #71, #74, #75, #76 | T3/T12/T14: protocolo, rangos, parser, telemetria, perdida de frames. |
| Vision RPi | #64, #65, #66, #68, #81, #120, #124 | T12/T13/T14/T15: pipeline, robustez de camara, dependencias, FPS, tensor/NMS. |
| Movimiento/control | #57, #58, #67, #121, #122, #125, #126, #127 | T13/T15: linea, giros, encoder, PID, performance real. |
| Rescate y scoring | #85, #86, #120, #123, #127, #128 | T1/T13/T15: requisitos RCJ 2026, victimas falsas, LED, salida de cuarto, estrategia de rescate. |
| Hardware/mecanica | #47, #52, #87, #96 | T4-T11: diseno, PCB/BOM, pinout, montaje y mantenimiento. |
| Proceso y evidencia | #91, #102, #106, #114, #117, #118 | T2/T7/T11/T14/T15: triage, asignaciones, banco, TEST_LOG. |

### Para 102/102, cada criterio debe tener este minimo

| Tema | Max | Evidencia obligatoria para aspirar a 100% |
|---|---:|---|
| T1 Requirements | 6 | Tabla desde reglas RCJ 2026: requisito, regla, decision de diseno, modulo, test/evidencia. Incluir victimas falsas, LED, rescue room, rampas, obstaculos, autonomia. |
| T2 Project Plan | 6 | Timeline con owners reales, issues/PRs, gates y fechas. No solo fases genericas. |
| T3 Integration Plan | 6 | Diagrama completo + matriz componente/requisito/interfaz. RPi-Teensy-PCB-sensores-actuadores. |
| T4 Mechanical diagrams | 6 | Fotos ortogonales + CAD/render + medidas + labels. |
| T5 Mechanical submodules | 6 | Chasis, drivebase, claw, corrales, deposito, mounts; interfaces y mantenimiento. |
| T6 Mechanical innovation | 6 | 1-3 innovaciones con foto/sketch, por que son propias, ventaja competitiva y prueba. |
| T7 Mechanical reliability | 6 | TEST_LOG con tests reales de pinza, rampas, golpes, depositos, mantenimiento. |
| T8 Electronic diagrams | 6 | Schematic, PCB, power tree, wiring photo, sensor map. Nada de placeholders. |
| T9 Electronic submodules | 6 | Power rails, reguladores, sensores, actuadores, UART, protecciones, switches. |
| T10 Electronic innovation | 6 | PCB propia: fuente, revision, fotos, BOM, conexion de controladores/sensores/actuadores. |
| T11 Electronic reliability | 6 | Tests de bateria, voltaje bajo carga, resets, ruido, conectores, banco. |
| T12 Software architecture | 6 | Flowchart Teensy, flowchart Main.py, serial sequence, rescue FSM, pseudocodigo, modulo/class diagram. |
| T13 Software innovation | 6 | YOLO/vision hibrida, FSM rescate, sensor fusion, recovery; con parametros y ventaja medida. |
| T14 Software reliability | 6 | Tests de parser, camara, serial, watchdog/timeouts, headless, systemd, fallas inyectadas. |
| T15 Performance evaluation | 6 | Metricas con metodo: corridas completas, FPS, pickup/deposit success, curvas, rescate, fallas y fixes. |
| T16 Clarity | 6 | Texto corto, factual, sin claims inflados, sin contradicciones con codigo actual. |
| T17 Formatting | 6 | Plantilla oficial 2026, PDF final limpio, figuras numeradas, tablas rotuladas, referencias. |

### Politica para llegar al 100% sin mentir

1. No se inventan tests. Se hacen, se reconstruyen con evidencia o se escriben como "planned".
2. No se prometen metricas sin metodo. Todo numero debe tener fecha/setup.
3. Si un issue critico sigue abierto, se documenta como riesgo controlado, no como problema resuelto.
4. Si una mejora no entra antes del submit, el TDP puede igual ganar puntos si muestra ingenieria madura: problema detectado, decision, tradeoff, plan y prueba parcial.
5. Para puntaje maximo, el TDP debe parecer escrito por un equipo que mide, decide y valida, no por un equipo que solo describe piezas.

### Orden duro de trabajo para transformar `TDP.md`

1. Sincronizar esta rama con `origin/main` o cherry-pick de PR #101 para traer `testing/TEST_LOG.md`.
2. Mover `TDP.md` a `docs/tdp/TDP-IITA-2026.md`.
3. Arreglar Markdown roto, headings y placeholders.
4. Crear estructura T1-T17 exacta.
5. Armar matriz Requirements (T1) y matriz Integration (T3).
6. Ejecutar #41: diagramas formales.
7. Ejecutar #96: BOM.
8. Poblar TEST_LOG con minimo 10 tests reales, distribuidos en MECH/ELEC/SW/PERF.
9. Incorporar fotos/diagramas/referencias.
10. Reescribir claims genericos como evidencia concreta.
11. Hacer self-review con la rubrica oficial 2026 y marcar puntaje estimado por cada T.

## Estado despues de la reescritura inicial

Fecha: 2026-05-22.

Archivos actualizados:

- `TDP.md`: reescrito como fuente principal T1-T17, con requisitos, plan, diagramas Mermaid, mecanica, electronica, software, IA, tests y performance.
- `docs/tdp/TDP-IITA-2026.md`: punto de entrada pedido por los issues de documentacion.
- `testing/README.md` y `testing/TEST_LOG.md`: recuperada la estructura de bitacora para evidencia T7/T11/T14/T15.
- `software/teensy/firmware/variables_doc.md`: convertido a aviso deprecado para evitar una copia vieja y contradictoria del TDP dentro del firmware.

### Estimacion honesta tras esta pasada

| Criterio | Antes | Ahora | Para 5-6 real |
|---|---:|---:|---|
| T1 Requirements | bajo | alto | Verificar reglas 2026 finales contra cada requirement. |
| T2 Project plan | bajo | medio-alto | Completar fechas reales/owners si el equipo quiere defenderlo oralmente. |
| T3 Integration | medio | alto | Renderizar diagramas en PNG/SVG para PDF. |
| T4 Mechanical diagrams | medio | medio-alto | Agregar fotos actuales del robot real, no solo CAD. |
| T5 Mechanical modules | medio | alto | Mantener links a CAD/STL. |
| T6 Mechanical innovation | medio | alto | Agregar 1 imagen/sketch de la garra y deposito. |
| T7 Mechanical reliability | bajo | medio | Cargar tests reales en `testing/TEST_LOG.md`. |
| T8 Electronic diagrams | medio | alto | Renderizar schematic/PCB y power tree en PDF. |
| T9 Electronic modules | medio | alto | Cerrar BOM oficial #96. |
| T10 Electronic innovation | medio | alto | Fotos PCB + explicacion de power rails. |
| T11 Electronic reliability | bajo | medio | Medir voltajes bajo carga y serial/sensores. |
| T12 Software architecture | medio | alto | Renderizar flowcharts/UML; asegurar que coinciden con codigo actual. |
| T13 Software innovation | medio | alto | Resolver runtime ONNX/TFLite y class-map antes de final. |
| T14 Software reliability | bajo | medio | Tests reales de camara, UART, crash, timeouts. |
| T15 Performance | bajo | medio | FPS real, pickup/deposit success, runDistance/runAngle error. |
| T16 Clarity | bajo | alto | Relectura final por coach/equipo. |
| T17 Formatting | bajo | medio | Pasar a template oficial DOCX/PDF. |

Estimacion actual si se entrega tal cual en Markdown: 55-70/102, dependiendo de cuan estricto sea el juez con evidencia y template.

Estimacion si se completan TEST_LOG + BOM + fotos + PDF oficial + fixes de consistencia: 90-102/102.

### Bloqueos restantes que no se pueden inventar

1. `testing/TEST_LOG.md` todavia no tiene tests reales. Sin esto no hay 100%.
2. Hay que decidir y documentar el runtime final de IA: docs dicen ONNX, `Main.py` actual usa TFLite.
3. Hay que validar el mapeo de clases de victimas: docs dicen `0 negro / 1 plateado`, pero el control actual debe compararse contra labels reales del modelo.
4. Hay que validar/fijar la mascara plateada: thresholds HSV no deben aplicarse sobre imagen BGR.
5. Hay que cerrar BOM oficial #96 con costo/cantidad/source final.
6. Hay que exportar a PDF usando la plantilla oficial RCJ 2026; si no se respeta formato/template, T17 puede caer fuerte.

## Evidencia visual agregada despues del benchmark Airborne

Fecha: 2026-05-23.

El TDP ahora incorpora cuatro assets visuales nuevos en `docs/tdp/assets/`:

- `robot-evolution-2023-2025.jpg`: secuencia de evolucion del robot, reconstruccion previa a competencia, robot listo y clasificacion mundial. Suma en T2, T4, T15 y narrativa de iteracion.
- `hardware-overview-2026.png`: diagrama visual de bateria, reguladores, motores, servos, sensores, Raspberry Pi y Teensy. Suma en T3, T8 y T9.
- `pcb-main-layout-2026.png`: layout de PCB custom con ruteo y forma de placa. Suma fuerte en T8 y T10.
- `electronics-schematic-2026.png`: esquematico con power, sensors, Teensy, COM, indicators y actuators. Suma fuerte en T8, T9 y T11.

Impacto estimado: estas imagenes suben el techo del TDP porque corrigen una de las diferencias mas claras con Airborne: evidencia visual embebida. Aun asi, no reemplazan los datos numericos de performance. Para acercarse a 95-100 sigue haciendo falta completar `TEST_LOG.md` con mediciones reales.

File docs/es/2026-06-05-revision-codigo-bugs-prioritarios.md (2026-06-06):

# Revisión de código — rama `Bugs-Prioritarios` (PR #129)

**Fecha:** 2026-06-05 · **Faltan 25 días** para Incheon (RCJ Rescue Line, 30-jun) · **Freeze de código: 2026-06-15 (10 días).**
**Auditado:** el código **LATEST** del equipo = rama `Bugs-Prioritarios` / PR #129 (tip `2976dca`), worktree `rcj-bugsprio-wt`. Son **2.336 líneas que ninguna auditoría previa miró** — es lo que va a Incheon si se mergea.

> ⚠️ **Esto es DISTINTO de las auditorías anteriores.** Las de resiliencia (2026-05-18), correctitud (2026-05-18) e integral (2026-05-31) fueron sobre `main` viejo (`c42e535`). Este documento es sobre el código NUEVO. Si un bug "ya estaba en el viejo" lo decimos, pero acá importa **qué corre hoy en el robot que compite**.

Equipo: **Laureano** (@Laumonteros, firmware Teensy) · **Lucio** (@luciouriel2011, visión RPi) · **Benjamin** (@benjaminvillagran, RPi + HW + banco).

---

## 1. Veredicto en 5 líneas

1. **El PR es una mejora neta real.** Cierra varios P0 que la auditoría previa marcaba abiertos: handshake 0xFA, timeouts de `runAngle`/`runDistance`/sensor color, Lock en cámara, autorestart systemd, recuperación global en Python. **Eso hay que protegerlo, no romperlo.**
2. **El miedo a "fixes muertos" es INFUNDADO.** El sistema de flags NO apaga nada (ver §3). La red de seguridad de resiliencia está **VIVA** en el firmware que se flashea.
3. **PERO hay bugs NUEVOS reales** en el código de evacuación/rescate (1 P0 + varios P1) que nadie había visto, porque ese código es nuevo.
4. **Dos huecos de seguridad quedaron abiertos a propósito o por descuido:** sin failsafe de RX en el Teensy (P0) y el flag #63 apagado desincroniza el serial tras cada maniobra (P1).
5. **Ningún cambio tiene corrida de banco documentada** (regla de oro #3 sin cumplir), y la evacuación nueva — que es la mitad del puntaje útil — es lo menos probado.

## 2. ¿Es seguro mergear PR #129?

**MERGEAR CON CONDICIONES — NO tal cual está.**

| Condición | Detalle |
|---|---|
| **Partir el PR en dos** | El diff toca 106 archivos (+5718 / −14137). El código real son ~6 archivos; el resto es docs/TDP y **borra 14.137 líneas de auditorías**. **No se puede revisar el código del robot enterrado entre 1205 líneas de markdown borrado.** Separar: PR-código (firmware + rpi) y PR-docs. |
| **Mergeable YA (bajo riesgo, mejora pura)** | `drivebase.cpp` (`pulseCount=0`), `camthreader.py` (Lock + daemon + `stream.release()` + `read()` con copy/None), `priority_fix_flags.h` + helpers de timeout/validación serial. |
| **Necesita BANCO antes del freeze** | Toda la rama `rutina=="evacuacion"` (main.cpp:1887-1956), los cambios de FSM de rescate, y `robot.service` (ruta a verificar en la Pi real). |
| **Arreglar antes de competir** | El P0 de RX failsafe, el P0 de path systemd, y el P1 de green_state sin resetear (ver §4). |

---

## 3. Estado de los fixes en el código nuevo

### ⭐ LO MÁS IMPORTANTE: el sistema de flags NO mata los fixes

Era el mayor temor y quedó **resuelto a favor**. En `priority_fix_flags.h:5` el master `kEnableAllPriorityFixes = false`, pero en `main.cpp:120-178` **cada helper usa OR, no AND**:

```cpp
bool fixIssue60Enabled() {
    return kEnableAllPriorityFixes || kFixIssue60RunDistanceTimeout;  // OR
}
```

Con el master en `false`, el `||` corta-circuita al **flag individual**. Como los individuales están en `true` (#57/#58/#59/#60/#61/#62/#67/#74/#75/#76/#112), **los fixes ESTÁN ACTIVOS**. El master no es un kill-switch: es un override "forzar-todo-on". **La red de seguridad existe en el binario que va a Incheon.** Único apagado: **#63** (`KeepSerialDuringMotions`, master false + individual false → muerto, ver §4 bug N-08).

> ⚠️ **Trampa semántica a futuro:** el naming engaña. Si alguien pusiera el master en `false` esperando "modo seguro sin fixes", se equivoca (los fixes siguen). Y poniéndolo `true` ya **no** podés apagar un fix individual. Debería llamarse `kForceEnableAllFixes`. **No tocar el master.** Para apagar un fix que en banco resulte contraproducente, bajá su flag individual.

### Tabla de fixes conocidos

| Bug | Estado | Evidencia (código nuevo) |
|---|---|---|
| **#67** init `pulseCount` motor | ✅ **CORREGIDO** | `drivebase.cpp:17` agrega `pulseCount = 0;` en el constructor `Moto`. Único cambio funcional del PR en drivebase. Aplicado siempre (sin gate). |
| **#72** handshake 0xFA | ✅ **CORREGIDO** | Teensy emite `Serial5.write(0xFA)` 20× en `setup()` (`main.cpp:1385-1389`). RPi lo consume como `TEENSY_BOOT` (`Main.py:33,163-166` → estado `'esperando'`). End-to-end OK. **Limitación:** es boot one-shot, **no** heartbeat (no detecta cuelgue en runtime). |
| **#58** case 12 fall-through a case 14 | ✅ **CORREGIDO** | `main.cpp:1695-1744`: `waitStart` + timeout 5000ms + `break` gateado por #58. Sin fall-through con #58=true. (Ver inconsistencia I-04: el break depende del flag, anti-patrón.) |
| **#60** `runDistance` sin timeout | ✅ **CORREGIDO** | `computeRunDistanceTimeoutMs` + break en ambas ramas FORWARD (1058) y BACKWARD (1092) + `stopOnExit`. |
| **#61 / #62** timeout color / init sensores | ✅ **CORREGIDO** | #61: `get_color_fresh` timeout 35ms, guards en legacy. #62: `handleBnoInitFailure`→`fatalSensorInitLoop` (LED/buzzer) en vez de `while(1)` mudo. |
| **#74** validar payloads serial | ✅ **CORREGIDO** | `serialPayloadOutOfRange()` (815-832) + `continue` en `serialEvent5` para speed/angle/green_state/silver fuera de rango. |
| **#75** telemetría serial | ✅ **CORREGIDO** | `maybePrintSerialTelemetry()` + contadores `serial_frames_rx`. **Solo observabilidad** (ver oportunidad y P0 N-01: el dato existe pero no alimenta ningún failsafe). |
| **#112** `runAngle` sin timeout | ✅ **CORREGIDO** | `computeRunAngleTimeoutMs` + break (`main.cpp:959-963`). Acota B8. |
| **B9** rojo HSV sin wrap | ✅ **CORREGIDO** | `Main.py:77-80` doble rango (`red1` H[0-7], `red2` H[170-179]) + `bitwise_or` sobre `hsv_frame`. Además fin-de-pista pasó a método robusto por bandas de filas (línea simple=10 / doble=11). |
| **B6** salida anticipada del cuarto | ✅ **CORREGIDO** (en `src/` real) | Se **eliminó** el `veces_deposit=2;` hardcodeado. Ahora arranca en 0 (reset en case 2, 1598) y sube solo en depósitos reales (1845/1867). **OJO:** sigue sin chequear pelotas y reintroduce riesgo por otra vía → ver N-04 (green_state) y N-05 (`==2` estricto). |
| **#57** rescate ambas ramas −90 | ⚠️ **CORREGIDO por reescritura, flag MUERTO** | El bloque viejo (ambas ramas −90) fue **borrado**. El rescate nuevo usa `runAngle(+45)`/`(−45)` por lado, correcto. **PERO `fixIssue57Enabled()` está definido y NUNCA se llama** (0 call sites) → flag huérfano engañoso. El bug desapareció; el flag miente. |
| **B8** `runAngle(180)` sin mirar signo | ⚠️ **PARCIAL** | `main.cpp:982-986`: para 180° sigue `robot.steer(speed,dir,1)` (siempre a derecha, ignora signo). **Acotado** por timeout #112 (ya no se cuelga), pero puede tomar el camino largo. |
| **B2** silver_mask BGR con umbrales HSV | ⚠️ **PARCIAL** | `Main.py:787` sigue `inRange(frame_resized, lower_silver_hsv, ...)` sobre **BGR** con umbrales nombrados HSV → máscara prácticamente ruido. **Mitigado** por el sensor APDS del Teensy que clasifica 'Plateado' (`get_color_fast`). Doble camino: el del sensor es robusto, el de visión sigue frágil. |
| **B1** PID `kp=0/ki=22` DIRECT | ❌ **NO CORREGIDO** (decisión válida) | `drivebase.h:30-31` idéntico al viejo. Integral puro agresivo. **NO es runaway:** `PID.cpp` tiene anti-windup (clamp `outputSum` 0-255). `255-_pwmVal` es **correcto** para el FIT0441 (PWM activo-bajo). Es el baseline tuneado, no una regresión. Ver oportunidad O-1. |
| **B4** `leer_yaw()` no asigna el global | ❌ **NO CORREGIDO** | `main.cpp:1181-1187`: declara `float yaw` LOCAL que tapa al global (1179). `avance_recto()` llama `leer_yaw()` como void y usa el global, que **queda en 0**. Idéntico al viejo. **Bloquea** la búsqueda por yaw en evacuación (ver O-3). |
| **B5** velocidad 55 en curva | ❌ **NO CORREGIDO** | `main.cpp:1682-1690` case 7: si `|steer|>0.7` → `robot.steer(55,...)`. Hardcodeado, idéntico al viejo. Ver O-1/O-2. |
| **B10** encoder 25 pulsos/cm | ❌ **NO CORREGIDO** (mitigado) | `main.cpp:1051` `encoder = 25*Distance` hardcodeado. **Field-calibrado** y documentado (`MEDICIONES_PENDIENTES.md`, validado vs 28.65 teórico, error medido 1-2cm). Acotado por timeout #60. Define la geometría del barrido de evacuación → recalibrar in-situ (O-4). |
| **#53** heartbeat serial continuo | ❌ **NO CORREGIDO** | Grep `heartbeat`/`0xFB` = 0. El 0xFA es boot one-shot. Sin detección de caída de enlace de ningún lado. **Raíz del P0 N-01.** |
| **#27** WDT hardware Teensy | ❌ **NO CORREGIDO** | Grep `WDT`/`watchdog` en `main.cpp` = 0. Si el firmware se cuelga en un `while` sin timeout (p.ej. case 1 esquiva, N-02), no hay reset automático. Ver O-resiliencia. |
| **taskDone** nunca vuelve a false | ❌ **NO CORREGIDO** | `main.cpp:80` init false; solo pasa a true en switch-off (1418). El `if(taskDone)` (1510) que envuelve TODA la FSM de acciones queda **permanentemente true** tras el primer toggle. Variable de "tarea en curso" ficticia. No protege re-entrar a una intersección ya procesada. |
| **FSM rescate no-bloqueante** | ❌ **CÓDIGO MUERTO** | `actualizarRescate()` + enum `RescateState` (257-431, ~175 líneas) se llama cada loop, pero `iniciarRescateNegra/Plateada` (los únicos que sacan de `IDLE`) **nunca se invocan** (0 call sites) → queda en `RESCATE_IDLE`. El rescate REAL es **inline-bloqueante** (1760-1886). Igual `Claw::pickupLeft/Right`. Tres niveles de "recolectar pelota" escritos, uno solo corre. |

---

## 4. Bugs NUEVOS detectados

> Estos son del código nuevo. No estaban en el viejo o se amplificaron con el uso intensivo en la evacuación nueva.

### P0 — riesgo de no completar la corrida

| # | Título | Archivo:línea | Qué pasa | Fix | Quién |
|---|---|---|---|---|---|
| **N-01** | **Sin failsafe de RX en el Teensy** | `main.cpp:1486-1490, 1765`; serialEvent5 `849-900` | El Teensy actúa sobre las globales `speed`/`steer` que setea la RPi. **NO hay chequeo de "hace cuánto que no recibo un frame".** Si la RPi se cuelga (cámara None, excepción de visión, cable suelto), el robot **sigue manejando con el último comando — típicamente avanzando — hasta que se baje el switch físico.** Se va de la mesa o choca a fondo. Es el agujero más grande de la red de seguridad. | `static unsigned long lastFrameMs` actualizado en serialEvent5 al completar frame (donde ya sube `serial_frames_rx`, 894). En `loop()` antes de actuar: `if (millis()-lastFrameMs > 400){ robot.steer(0,FORWARD,0); }`. **Gatearlo con un flag nuevo** para probarlo en banco antes del freeze (desenchufar TX de la RPi y ver que frena). ~1-2h. | **Laureano** |
| **N-02** | **systemd apunta a un archivo que no existe** | `systemd/robot.service:8-9` | `ExecStart=/usr/bin/python3 /home/iita/Desktop/main.py` (minúscula) pero el repo es `final_rpi/Main.py` (**M mayúscula**, otra carpeta). Linux es **case-sensitive**: si en la Pi el archivo es `Main.py`, systemd falla con "No such file" y con `Restart=always` **loopea cada 2s eternamente sin arrancar nunca el robot.** Agravado: `Main.py` hace `from camthreader import *` → ese archivo debe estar en el mismo cwd, y el modelo TFLite está hardcodeado en otra ruta (`/home/iita/Documentos/...`). 3 paths que no cierran. | Decidir UNA convención y alinear `ExecStart` + `WorkingDirectory` con la ruta real desplegada. **Probar en la Pi real:** `sudo systemctl start robot && systemctl status robot`, matar el proceso y ver que reinicia y **levanta este código**. Verificar `User=iita` en grupos `dialout` (serial) y `video` (cámara). Escribir un README de deploy. | **Benjamin** (con Lucio) |

### P1 — pérdida de puntaje o comportamiento errático

| # | Título | Archivo:línea | Qué pasa | Fix | Quién |
|---|---|---|---|---|---|
| **N-04** | **`green_state` nunca se resetea tras depositar/recolectar → re-disparo del mismo evento** | `main.cpp:1768,1794` (negra/plateada) y `1827,1847` (verde/rojo) | Los bloques de rescate ejecutan la acción pero **NUNCA resetean `green_state`** (solo la RPi lo cambia). El loop itera cada pocos ms; si la RPi no mandó valor nuevo, en la próxima vuelta `green_state` sigue 6/7/8/9 y **se re-ejecuta toda la secuencia** (180°+ir a pared+depositRight+runDistance 64cm, o recolección completa). **Doble/múltiple depósito de la misma esquina**, `veces_deposit++` por el mismo evento → la salida `==2` puede alcanzarse re-disparando UNA esquina. Pérdida de pelota/penalización. | Resetear `green_state=0` al final de cada bloque de acción de rescate (igual que en línea se hace `action=7`). El bloque de evacuación (1952) ya lo hace bien — copiar el patrón. Idealmente exigir frame nuevo de la RPi antes de repetir. Banco: un comando de esquina = exactamente un depósito. | **Laureano** |
| **N-05** | **`veces_deposit == 2` estricto: si se sobrepasa, el rescate no sale nunca** | `main.cpp:1870` | Con el bug N-04, `veces_deposit` puede saltar de 1 a 3. La **igualdad estricta** `==2` nunca se cumple → el robot queda atrapado en `while(rutina=='rescate')` depositando hasta apagar el switch. **No hay timeout global de rescate** (existe `tiemporescate=millis()` en 1660 pero **nunca se chequea**). | Usar `>= 2`. Y cablear un timeout global usando el `tiemporescate` ya declarado: tras N segundos forzar `rutina='evacuacion'`. Combinar con N-04. | **Laureano** |
| **N-06** | **`right_distance==0` (dropout del ultrasonido) dispara giro 90° en cada lectura nula** | `main.cpp:1906-1914` | `if (right_distance == 0 \|\| (right_distance-last_right_distance)>30)` → avanza + gira 90° derecha. `NewPing.ping_cm()` devuelve **0 cuando no hay eco** (muy común en pared inclinada/esquina). Cada lectura 0 → giro espurio. En el cuarto de evacuación = pierde la trayectoria de barrido. | Tratar `right_distance==0` como **lectura inválida** (no como "pared lejos"): ignorar/repetir o usar el último válido. Separar "abertura real" (salto sostenido en N lecturas válidas) del dropout. | **Laureano** |
| **N-07** | **`right_jump_counter` nunca se incrementa → rama de recuperación de evacuación MUERTA** | `main.cpp:1918` (lee `>=3`); decl `108`; reset `1417,1921` | `if (right_jump_counter >= 3)` dispara una recuperación, pero el contador **solo se declara y se resetea — NUNCA hay un `++`** en todo `main.cpp` (verificado por grep). La condición jamás se cumple, la rama no corre nunca. El wall-following queda sin el debounce que el contador pretendía. | Definir la intención: incrementar `right_jump_counter` donde se evalúa el salto de pared (1906) y resetear cuando se estabiliza; **o** borrar la rama 1918-1924 para no dar falsa sensación de cobertura. **Decidir UN solo barrido.** | **Laureano** |
| **N-08** | **#63 apagado: el control queda SORDO al serial durante TODO movimiento bloqueante** | flag `priority_fix_flags.h:13`; `main.cpp:913-924, 955-958, 1072-1082, 658-661` | `fixIssue63Enabled()=false`. En cada `runTime/runAngle/runDistance/get_color_fresh`, la rama que procesa serial es `if (... && fixIssue63Enabled()) serialEvent5();` y el **else hace `Serial5.read()` de UN byte y lo TIRA**. Durante maniobras de 1-3s, los bytes de la RPi se descartan de a uno y **desincronizan el parser de framing** (se comen sync bytes 252-255). Al volver al loop, `speed/steer/green_state` están viejos y el parser puede estar corrido. **Causa raíz del comportamiento errático al reanudar línea tras una intersección.** Expone además el `write_timeout` del lado RPi (ver N-12). | Poner `kFixIssue63KeepSerialDuringMotions=true` (los `runAngle/runTime` usan parámetros **locales**, no las globales, así que es **seguro**). Probar en banco que no rompa el timing de giros. Mínimo de bajo riesgo si preocupa: cambiar el else por un `while` que drene todo el buffer, o `Serial5.clear()` al salir de la maniobra. | **Laureano** |
| **N-09** | **`front_distance<12` pisa la acción de verde en la misma iteración** | `main.cpp:1515-1546` | Cadena de `if` **sin else**: green→action, luego `if(front_distance<12) action=1` (esquiva) pisa el verde. En una **T con doble verde** (giro 180), la pared del fondo suele estar a <12cm → hace **esquiva random en vez del 180**. Pierde la intersección de verde. | Reordenar con prioridad explícita con `else-if`: **rescate(plateado) > verde > obstáculo > linetrack**, o chequear `green_state==0` antes de dejar que `front_distance` dispare la esquiva. 30min + banco. | **Laureano** |
| **N-10** | **Posible doble-inversión de clases YOLO (víctima viva/muerta al revés)** | `Main.py:324` vs `654-655` | `CLASS_NAMES=['negro','plateado',...]` (cls0=negro, cls1=plateado). Pero `cls==0 → ball_type="silver"` y `cls==1 → "black"`. O sea **cls0 (nombre 'negro') se trata como SILVER** y viceversa. Doble inversión que **puede cancelarse o no** según el orden REAL de clases del `.tflite` entrenado (modelo NUEVO `best (2)_float32.tflite`, sin metadata verificado). Si está cruzado: clasifica viva/muerta al revés → deposita en zona equivocada → **pierde el multiplicador ×1.4.** | Verificar contra el `metadata.yaml` del modelo desplegado el índice real de plateado vs negro. Alinear `CLASS_NAMES` + mapeo `ball_type` (654-655) + green_state que espera el Teensy. **Banco:** pelota plateada real → confirmar que ejecuta la rama plateada (sortLeft) y deposita en zona de vivas. | **Lucio** |
| **N-11** | **NameError por `cx_black` sin asignar en el camino por DEFECTO del bloque verde** | `Main.py:806-824` (default OFF por `:15`) | `ENABLE_CX_BLACK_GUARD` defaultea a `'0'` → corre la rama ELSE (812-814): `cx_black` solo se asigna si hay negro en filas `[90:]`; si no, queda **sin definir** pero `valid_green_reference=True`. Si el ratio negro-sobre-verde supera 0.32 (816), líneas 822/824 leen `cx_black` → **NameError**. Escenario real: marca verde de T con la línea negra que no llega al borde inferior. La excepción sube al `except` global → `[FATAL]`, frena y resetea a `'esperando'` → **pierde la corrida en plena intersección.** Fix de 1 carácter. | Activar el guard por defecto: `Main.py:15` → `os.environ.get('ENABLE_CX_BLACK_GUARD','1')=='1'`. **O** inicializar `cx_black=None` antes del if/else y agregar `and cx_black is not None`. Validar con video de T donde la línea negra no llegue al borde inferior. | **Lucio** |
| **N-12** | **`send_frame` sin try/except: un `write_timeout` de 50ms tira el robot a 'esperando'** | `Main.py:101-119` (write 110-111; timeout `:70`) | El puerto abre con `write_timeout=0.05`. `ser.write()+flush()` **sin try/except**. Si el Teensy no drena su RX por 50ms (justo lo que pasa con **#63=false**, N-08), `write` lanza `SerialTimeoutException` → sube al `except` global → `[FATAL]` + `estado='esperando'` + sleep(1s). **Abandona el rescate/línea ante un hipo de escritura**, plausible en pista por #63. | Envolver `write/flush` en try/except; ante timeout, loguear y reintentar 1× tras `reset_output_buffer()` o devolver sin matar el estado. Subir `write_timeout` a ~0.2s. **Coordinar con N-08:** activar #63 ataca la causa raíz. | **Lucio** + Laureano (#63) |
| **N-13** | **`capture_thread` sin try/except + `frame_q.get()` sin timeout = zombi irrecuperable** | `Main.py:455-463` y `469` | El #111 blindó `infer_thread`, pero `capture_thread` **NO** tiene try/except: si `cv2.rotate` falla o cualquier excepción, el hilo de captura **muere callado**. `frame_q` deja de llenarse e `infer_thread` queda bloqueado para siempre en `frame_q.get()` (469, **sin timeout**). `main_loop` da `queue.Empty` indefinido → **robot congelado en rescate/evacuación sin watchdog que lo saque.** Pérdida total de la corrida. | Envolver `capture_thread` en try/except que ante fallo haga `stop_event.set()` + `frame_q.put(None)` (espejo de infer_thread). Y/o `frame_q.get(timeout=...)` con manejo de `Empty`. Banco: simular cámara colgada en rescate y confirmar salida en <2s. | **Lucio** |

### P2 — robustez / deuda

| # | Título | Archivo:línea | Qué pasa / Fix | Quién |
|---|---|---|---|---|
| **N-14** | Busy-loops de case 1 (esquiva) sin timeout NI serial | `main.cpp:1561-1570, 1576-1585` | El `while` de esquiva solo sale si `get_color_fast()=="Negro"`. Si nunca lee negro (sensor sucio, esquina sin negro) → **gira en círculo para siempre**. Además `serialEvent5()` está **comentado** dentro (1564,1579). NO recibió timeout en la tanda de fixes. **Fix:** agregar `if((millis()-t0)>3000) break` como #58/#112, y descomentar/llamar `serviceMotionBackgroundTasks()`. | **Laureano** |
| **N-15** | Bloques de depósito hacen retroceso a fin de carrera **sin timeout** | `main.cpp:1831-1837, 1851-1857` | `while(digitalRead(32)==0){ steer(15,BACKWARD); if(FCL==HIGH&&FCR==HIGH) break; }`. Si un FC no cierra (falla mecánica, esquina mal alineada, víctima trabada) → **retrocede contra la pared indefinidamente.** Patrón opuesto a los que ganaron timeout. **Fix:** `if(millis()-start>2500) break`. | **Laureano** |
| **N-16** | Esquiva con `random()` sin seed → secuencia idéntica cada corrida | `main.cpp:1555-1556` | Sin `randomSeed()` en setup (verificado). En Teensy `random()` sin seed da **siempre la misma secuencia** tras reset → esquiva siempre para el mismo lado. Predecible y no mira `left/right_distance` que ya lee. Ver O-esquiva. | **Laureano** |
| **N-17** | `runDistance` arranca con sacudida fija BACKWARD+FORWARD 20ms | `main.cpp:1048-1049` | `runTime(30,BACKWARD,0,20)`+`runTime(30,FORWARD,0,20)` antes de resetear encoders. Es un tirón anti-fricción pero mete ~40ms de movimiento **no medido** y ~0.5cm de retroceso no contabilizado **por cada avance**. En evacuación se llama muchas veces (1907,1913,1938,1949) → **deriva acumulada.** **Fix:** medir deriva tras 10 `runDistance`; reducir a 10ms o compensar. | **Laureano** |
| **N-18** | `computeRunDistanceTimeoutMs` puede abortar el avance a baja velocidad | `main.cpp:236-244` | Estima `max(8, speed*3/4)` cm/s + margen 3/2 + 500ms. A `speed=15-20` con carga (pelota, rampa) el robot va **más lento** → el timeout puede dispararse antes de llegar → break silencioso → **robot mal posicionado en evacuación.** **Fix:** factor 2× o +1000ms para velocidades <25; loguear cuando dispara para distinguir "llegué" de "me rendí". | **Laureano** |
| **N-19** | `accionNegro()` saca de evacuación al primer negro | `main.cpp:1143-1151` desde `1891` | `accionNegro()` hace `rutina='linea'`. En cuanto ve **cualquier** negro (el borde negro del cuarto, que siempre está) sale de evacuación. `get_color_fast()` es 1 muestra sin filtro → falso negro (sombra, borde) → **loop: entra evac → negro → línea → re-detecta plateado → rescate de nuevo.** **Fix:** confirmación multi-muestra antes de `accionNegro`, o no dejar que cambie `rutina` durante evacuación. Modelar evacuación como FSM explícita. | **Laureano** |
| **N-20** | Asimetría sospechosa depósito verde (64cm) vs rojo (0cm) | `main.cpp:1844` vs `1863` | Verde: `runDistance(30,FORWARD,4+60)` = 64cm. Rojo: `runAngle(45)+runTime(500)+runAngle(-45)`, **sin avance equivalente**. El `4+60` es número mágico. En el `evacuation.cpp` viejo **ambos** hacían `runDistance(...,40)` → el comportamiento cambió. Sin banco no se sabe si es mejora o regresión. **Fix:** documentar la geometría, reemplazar `4+60` por constante nombrada, validar ambas secuencias en banco. | **Laureano** |
| **N-21** | `salida final green_state==10` comentada y rota | `main.cpp:1879-1884` | Bloque comentado con error de sintaxis (`estado == "salida"` con `==` y variable inexistente) que **no compilaría** si se descomenta. La salida real del cuarto depende de `accionNegro` (N-19), frágil bajo el destello de la regla 3.9. **Fix:** borrar el bloque roto y definir/probar UNA condición de salida robusta. | **Laureano** |
| **N-22** | `print(area)` incondicional en el hot-loop de línea | `Main.py:842` | Dentro de `for contour in silver_contours:`, un `print(area)` sin guard, cada frame por cada contorno. Con `PYTHONUNBUFFERED=1` (systemd) es **I/O síncrono al journal** → recorta FPS y ensucia logs. **Fix:** borrar o gatear con `if SHOW_DEBUG_WINDOWS`. | **Lucio** |
| **N-23** | `record=True` fuerza `cv2.imshow` de debug | `Main.py:58, 896-897` | `record` pasó de False a **True**. Hoy gateado por `SHOW_DEBUG_WINDOWS` (headless OK), pero si alguien lanza `Main.py` desde sesión gráfica/VNC con `DISPLAY` → abre 4-5 ventanas a 30+ FPS robando CPU en plena corrida. Cambio de debug que no debe ir a competencia. **Fix:** `record=False`, o flag `COMPETITION=1` que apague todos los imshow. | **Lucio** |

---

## 5. Inconsistencias a corregir

> El hilo común es **código muerto que aparenta estar vivo** — el equipo puede estar tuneando fantasmas. Limpiar esto baja la superficie de bug a 10 días del freeze.

| # | Inconsistencia | Dónde |
|---|---|---|
| **I-01** | **`test/evacuation.cpp` (1205 líneas) es CÓDIGO MUERTO y peligroso.** Tiene su propio `setup()/loop()`. `platformio.ini` **no** define `build_src_filter` → PlatformIO compila **solo `src/`**. NO entra al binario. PERO: (a) es una **copia STALE** del main viejo (`get_color()` bloqueante, sin validación serial, sin timeouts, **sin** `priority_fix_flags.h`); (b) tiene el bug B6 que el `src` vivo ya **no** tiene (`veces_deposit=2;` hardcodeado en `:1113` justo antes del `if`); (c) si alguien lo sube a `src/` por error, **sube firmware sin NINGÚN fix.** Las "1205 líneas nuevas" del diff son en su mayoría este archivo muerto — el cambio real de lógica es mucho menor. | `test/evacuation.cpp:1-1205` vs `src/main.cpp:1887-1956` |
| **I-02** | **Flags y variables huérfanas que engañan.** `fixIssue57Enabled()` definido, **0 call sites** (el equipo cree que #57 está "aplicado por el flag" y el flag no controla nada). `#67` se aplica **sin** gate (`drivebase.cpp:17`) → el flag es decorativo. `evacuacion_straight` (decl 106, solo se resetea) y `alineado` (101, solo `=false`) son zombis. `lastTurn`/`turnCooldown=600` (52-53) declarados, **nunca usados** (anti-rebote de verde a medias). | `main.cpp:120-124, 101, 106, 52-53` |
| **I-03** | **`veces_deposit` y `ball_counter` inicializan en 2** (el valor "terminado"), no en 0. Funciona porque se resetean al entrar a rescate (1597-1598), pero **el reset de switch-off (1407-1418) NO los toca.** Si el operador apaga/reenciende el switch **durante** rescate (común en competencia), quedan en valor arbitrario → depósito/salida con conteo corrupto. | `main.cpp:103-104, 1407-1418, 1597-1598` |
| **I-04** | **Break de `case 12` depende del flag #58 para no caer por fall-through a `case 14`** (giro 180). Control de flujo de un `switch` acoplado a un feature flag = anti-patrón. Inofensivo hoy **solo** porque `green_state==14` nunca llega de la RPi (código inalcanzable). **Fix:** `break` incondicional, dejar el flag solo para el timeout. | `main.cpp:1740-1744` |
| **I-05** | **`case 12` / `green_state 14-17` es código inalcanzable.** La RPi en línea solo emite `green_state ∈ {0,1,2,3,10,11}` (verificado `Main.py:790-874`). El `case 12` (50+ líneas con su timeout #58) **nunca corre en competencia.** El #58 protege código muerto. **Fix:** confirmar con Lucio que fue feature abandonada y borrar. | `main.cpp:1536-1539, 1695-1744` |
| **I-06** | **Línea roja de fin por VISIÓN se descarta.** La RPi manda `green_state=10` (simple) / `11` (doble), pero el firmware en rutina línea **nunca lee 10/11** (el switch solo maneja 0/1/2/3/14). Solo corta si el APDS físico clasifica 'Rojo' (`color_detected=="Rojo"`, 1504). Se tira información que la RPi ya calcula. Ver O-fin-pista. | `main.cpp:1504-1508` vs `Main.py:871-874` |
| **I-07** | **Tres implementaciones de clasificación de color en el firmware vivo:** `get_color_fast`/`update_color_nonblocking` (la usada), `get_color_old` (676) y `get_color_blocking_legacy` (731), las dos últimas **0 call sites**. Encima los umbrales de 'Rojo' **difieren entre el `print` y el `return`** en la legacy. Confunde el mantenimiento de la calibración. | `main.cpp:676-729, 731-802` |
| **I-08** | **Doble trigger de entrada a rescate con criterios distintos:** visión (`Main.py:838` silver_mask BGR + área>50 → `silver_line=1`) y sensor color Teensy (`main.cpp:1494` `get_color_fast=='Plateado'`). Coexisten sin fuente de verdad clara. Si uno da falso positivo, la entrada a la zona es errática. | `Main.py:838` vs `main.cpp:1494` |
| **I-09** | **Doc duplicada en el mismo PR que dice deduplicar.** `variables_doc.md` se vació marcándose "Deprecated TDP Copy" apuntando a `../../../TDP.md`, pero el PR agrega `TDP.md` en la raíz **Y** `docs/tdp/TDP-IITA-2026.md` (mismo contenido, 458 líneas c/u). Se viola "una sola fuente de verdad" en el mismo PR. | `TDP.md` y `docs/tdp/TDP-IITA-2026.md` |
| **I-10** | **Contrato de rangos desactualizado.** El comentario dice `green_state: 0..20` (`Main.py:22-23`) pero el código usa hasta 11. Verificar que `SERIAL_MAX_GREEN_STATE` (#74) sea ≥ los valores reales o se rechazarán green_states válidos — y `serialPayloadOutOfRange` hace `continue` **sin** resetear `serial5state`, desincronizando el frame siguiente. `cut_line` (778,781) se calcula y nunca se usa. | `Main.py:22, 778` vs `main.cpp:881` |

---

## 6. Oportunidades de mejora competitivas (ojo de campeón)

> Priorizadas por impacto en PUNTAJE. El scoring 2026 multiplica TODO el campo por **×1.4 por cada víctima viva evacuada**. Un robot que termina la línea pero falla la evacuación deja más puntos sobre la mesa que cualquier optimización de velocidad.

### 🎯 PALANCA #1 — Blindar la EVACUACIÓN (máximo leverage)

Es la mitad del puntaje útil y hoy es lo más frágil. Tres agujeros encadenados que ningún campeón aceptaría:
- **(a) Cobertura del cuarto a merced del azar.** `avance_recto()`, `lado_pared()`, `pelotita()`, `esquinas_negro[]` están **definidas pero MUERTAS** (0 call sites). El robot solo reacciona a lo que ve la cámara, **sin barrido sistemático del perímetro ni memoria de qué víctimas ya recogió.** Pelota en esquina fuera de cuadro = no se recoge nunca.
- **(b) Depósito a 180° fijo** (`main.cpp:1830,1850`) que asume la zona siempre enfrente. En zona asimétrica (los jueces la arman así) **deposita al aire.**
- **(c) Salida final sin implementar robustamente** (N-21).

**Leverage realista en 10 días — NO rediseñar, pero SÍ:** (1) cablear `avance_recto()` como modo búsqueda cuando la cámara no ve pelota — **requiere antes arreglar B4** (`leer_yaw` no asigna el global yaw); (2) hacer **20 corridas de evacuación cronometradas** midiendo tasa de captura y de depósito-en-zona-correcta, y tunear timings **con datos, no a ojo**. *Impacto: ALTO. Una corrida de ~30 pts de línea pasa a 30×1.4×1.4≈59 pts.* → **Laureano + Lucio.**

### 🎯 PALANCA #2 — Calibración de color robusta para la luz de Incheon (consistencia)

Lo que mata corridas en un estadio nuevo no es la estrategia, es que los umbrales calibrados en **Salta** no matchean la luz de **Songdo**. Tres sistemas de color con umbrales hardcodeados que se van a desincronizar: (a) `Main.py` BGR/LAB/HSV fijos (71-80) + **silver_mask en BGR con umbrales HSV (B2)**; (b) APDS9960 en Teensy con `known_colors[]` y thresholds mágicos (`c>1700`, `R/C>0.240`); (c) `CLASS_THRESH` de YOLO.

**Acción en 10 días:** (1) **fijar exposición y balance de blancos de la cámara** — hoy el auto-exposure "bombea" cuando entra plateado/blanco brillante y arruina las máscaras (el `anti_flash` ataca el síntoma; la causa es el auto-exposure). Son ~2 líneas de `cv2.CAP_PROP`; (2) escribir un **checklist de recalibración para el pit** (10-20s antes de cada ronda); (3) cargar umbrales desde JSON editable sin recompilar. *Impacto: ALTO para CONSISTENCIA — bajar la varianza entre corridas vale más que subir el máximo.* → **Lucio + Benjamin.**

### 🎯 PALANCA #3 — Convertir la novedad ya escrita en evidencia medida para el TDP

El TDP pesa **12% del total** y la rúbrica 2026 agregó "Reliability Tests & QA". El equipo YA tiene el activo de novedad más fuerte **escrito y corriendo**: el pipeline **anti-destello** (respuesta directa a la regla 3.9 de LEDs intermitentes) y el diseño de **validación multimodal de víctima** (visión+conductividad+reflectancia, regla 3.10). Ningún equipo de referencia (Overengineering², Airborne, Danesh) documenta esto porque compitieron bajo reglas 2024/2025. **Es el relato incopiable.** Pero hoy es "diseñamos", no "medimos": el TEST_LOG está casi vacío y **la conductividad NO está embarcada** (pin 26 no se lee).

**Alto ROI en 10 días:** (1) **implementar la conductividad** — ~15 líneas + 1 pin + 2 cables (ya documentado) → convierte el claim en feature real que rechaza víctimas falsas (regla 3.10); (2) grabar 15-20 frames con destello (una linterna), correr detección con/sin `anti_flash`, meter la tabla en TEST_LOG → N1 pasa de "diseñamos" a "diseñamos y validamos" (la diferencia entre 3 y 6 en la rúbrica). **Cuidado de credibilidad:** presentar SOLO lo embarcado como "el robot hace"; lo demás como "en integración". Un juez de mundial desarma claims inflados. → **Benjamin + Lucio.**

### Otras oportunidades (orden de impacto)

- **O-1 — Sintonizar un Kp real en el PID** (hoy `kp=0/ki=22`, integral puro). Un Kp pequeño da respuesta inmediata al error y mejora consistencia rueda-a-rueda y trazado en curvas. *Riesgo medio (re-test de las 4 ruedas). Solo si se hace ANTES del 15-jun o no se toca.* → **Laureano.**
- **O-2 — Speed scheduling proporcional en línea** en vez de dos velocidades 25/55 (B5): frenado progresivo al entrar en curva, mínimo en el ápice. Menos overshoot (salirse de la línea) + más velocidad en recta. → **Laureano.**
- **O-3 — Recuperación de línea perdida** (line-search): al perder negro, hoy la RPi manda `angle=0` y el robot sigue recto a ciegas. Un barrido ±con la IMU buscando negro salva baldosas en gaps. *Requiere B4 arreglado.* → **Laureano + Lucio.**
- **O-esquiva — Esquiva por sensor en vez de `random()`** (N-16): el robot YA lee `left/right_distance`. Mínimo: `lado = (left_distance > right_distance) ? izq : der`. El random ciego falla ~50% cuando el espacio está del otro lado. → **Laureano.**
- **O-fin-pista — Cerrar fin de pista por visión** (I-06): aprovechar `green_state 10/11` que la RPi ya manda, redundante con el APDS. Parada confiable en la línea roja de fin. → **Laureano + Lucio.**
- **O-resiliencia — Failsafe bidireccional + WDT hardware.** Convertir el 0xFA en heartbeat periódico (cada ~200ms ambos lados) cierra N-01 **y** el caso inverso (Teensy colgado). Armar el **WDT_T4** del Teensy con `feed()` en loop + while largos: ataja TODOS los cuelgues, incluso los no previstos (case 1, N-14). *Práctica estándar de equipos top, costo bajo.* → **Laureano** (+ Lucio para el lado RPi).
- **O-presupuesto — Recortar delays de pinza sobre-dimensionados.** Cada pelota encadena ~8 `nonBlockingDelay` de 1000-1400ms ≈ **9-10s/pelota ×3 ≈ 30s** quieto. **Cronometrar la corrida completa**; si no alcanza para 3 pelotas+2 depósitos+salida, recortar delays (varios 1000ms pueden ser 600-700ms si el servo ya llegó) y **priorizar las 2 vivas** (valen el multiplicador) sobre la muerta. *Regla de oro: evacuar 2 vivas > intentar 3 y quedarse sin tiempo.* → **Laureano + Benjamin (banco con cronómetro).**

---

## 7. Reparto por persona (antes del freeze del 15-jun)

### 🔧 Laureano (@Laumonteros) — firmware Teensy
**Orden de prioridad:**
1. **N-01 — Failsafe de RX (P0).** Deadman `lastFrameMs` + freno si `>400ms` sin frame, gateado por flag nuevo. Banco: desenchufar TX de la RPi → debe frenar. *Es el agujero más grande.*
2. **N-04 + N-05 — Reset de `green_state` tras depositar + `>=2` + timeout global de rescate.** El re-disparo de depósitos es pérdida directa de puntaje. Banco: un comando de esquina = un depósito.
3. **N-08 — Activar #63** (`kFixIssue63KeepSerialDuringMotions=true`). Mata el comportamiento errático tras intersecciones y cierra N-12. Banco: medir que no rompa timing de giros.
4. **N-06 + N-07 — Filtrar `right_distance==0` + decidir el barrido (cablear o borrar `right_jump_counter`).** Wall-following de evacuación.
5. **N-09 — Reordenar prioridad** verde > obstáculo (else-if).
6. **N-14 + N-15 — Timeouts faltantes** (case 1 esquiva, while de fin de carrera del depósito).
7. **Limpieza (I-01, I-02): borrar `test/evacuation.cpp`, flag #57 huérfano, variables zombi.** *No mergear 1200 líneas muertas de la lógica más crítica.*
8. Si queda tiempo y se valida en banco: **O-1 (Kp), O-esquiva, O-fin-pista.**

### 👁️ Lucio (@luciouriel2011) — visión RPi
**Orden de prioridad:**
1. **N-10 — Verificar el orden REAL de clases del `.tflite`** contra el metadata. Si está cruzado, deposita víctimas en zona equivocada (pierde ×1.4). Banco con pelota plateada real.
2. **N-11 — Activar el guard de `cx_black`** (`ENABLE_CX_BLACK_GUARD` default `'1'`). Fix de 1 carácter que evita perder corridas por NameError en T.
3. **N-12 + N-13 — try/except en `send_frame` y `capture_thread`** + timeouts en colas. Evita abandonos de corrida por hipos de serial/cámara.
4. **B2 / PALANCA #2 — Decidir la fuente de verdad del plateado:** mover silver_mask a HSV real **o** confiar 100% en el APDS y borrar la rama de visión (no enviar `silver_line=1` espurios). Validar con la cinta plateada real.
5. **Cámara: fijar exposición + WB manuales** (causa raíz del bombeo de máscaras). ~2 líneas.
6. **N-22 + N-23 — Sacar `print(area)` del hot-loop y `record=False`** para competencia.
7. PALANCA #3 (medición visión): grabar frames con/sin destello para el TEST_LOG.

### 🔌 Benjamin (@benjaminvillagran) — RPi + HW + banco
**Orden de prioridad:**
1. **N-02 — Arreglar el path de `robot.service` (P0).** Alinear `ExecStart`/`WorkingDirectory` con la ruta y nombre reales en la Pi (case-sensitive). **Probar `systemctl start/status`, matar el proceso, ver que reinicia y levanta ESTE código.** Verificar `iita` en grupos `dialout`+`video`. Escribir README de deploy. *Si esto falla, el robot no arranca en la mesa.*
2. **Single source of truth de paths:** repo == lo que corre en la Pi. Sacar el hardcode del modelo TFLite a una env var. Confirmar que `Main.py` + `camthreader.py` + modelo estén en el cwd correcto.
3. **PALANCA #3 — Embarcar la conductividad** (pin 26, ~15 líneas + 2 cables): convierte el mejor relato de TDP en feature real (regla 3.10).
4. **Banco de evacuación (PALANCA #1):** correr y cronometrar las 20 corridas con Laureano, llenar `testing/TEST_LOG.md`. *Regla de oro #3: ningún fix de evacuación se mergea sin banco documentado.*
5. **O-presupuesto:** cronometrar la corrida completa de evacuación con Laureano.
6. Endurecer `robot.service`: `StartLimitBurst`, esperar `/dev/serial0` y cámara, `Environment=ENABLE_CX_BLACK_GUARD=1`.

---

## 8. Cierre del coach — las 3 cosas de mayor impacto en 25 días

Equipo: este PR es un salto real respecto del robot que auditamos en mayo. Cerraron P0 de resiliencia, el handshake, los timeouts, el threading de cámara. **Eso ya está ganado — no lo rompan en el apuro.** Usen los flags individuales como red: si un fix nuevo rompe algo en Incheon, se apaga **su** flag, no se revierte código.

Ahora, dónde ponemos las fichas en estos 25 días, en orden:

1. **TAPAR LOS DOS P0 ESTA SEMANA.** El robot que se va de la mesa cuando la RPi se cuelga (**N-01**) y el autostart que no encuentra su propio archivo (**N-02**) son la diferencia entre competir y mirar. Son de bajo riesgo y se prueban en banco en una tarde. No lleguen al freeze sin esto.

2. **BLINDAR LA EVACUACIÓN — es la mitad del puntaje.** El multiplicador ×1.4 por víctima viva vale más que cualquier optimización de velocidad. No rediseñen: arreglen **B4** (yaw), cableen un barrido mínimo (**PALANCA #1**), arreglen el re-disparo de depósitos (**N-04/N-05**), y hagan **20 corridas cronometradas** tuneando con datos. Hoy la evacuación está a merced del azar y es lo menos probado.

3. **CONSISTENCIA > MÁXIMO: calibración de color in-situ + medir para el TDP.** Lo que mata robots en un mundial es que andan en casa y fallan en la cancha por la luz. **Fijen exposición/WB** (2 líneas, causa raíz del bombeo) y lleguen con un **checklist de recalibración para el pit**. Y de paso, **embarquen la conductividad** y graben las pruebas de destello: convierten el relato de novedad más fuerte que tienen (12% del TDP) de "diseñamos" a "medimos".

**Disciplina final:** todo lo que se toque va a banco y al `TEST_LOG.md` antes de mergear (regla de oro #3). Partan el PR #129 en código y docs para poder mergear el código seguro YA. Y no toquen el PID ni el master flag a menos que tengan una corrida de banco que lo justifique.

A ganar experiencia en Incheon — y a llegar con el robot **consistente**, que es lo que separa el podio.

— El coach

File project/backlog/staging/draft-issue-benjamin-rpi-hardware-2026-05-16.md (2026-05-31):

## Cluster RPi + hardware — para Benjamin (codeowner RPi/hardware, dueño del banco)

> **DOCUMENTO HISTÓRICO (2026-05-16).** Estado de proyecto y régimen vigente: ver [`docs/es/ESTADO-ACTUAL-2026-05-31.md`](../../../docs/es/ESTADO-ACTUAL-2026-05-31.md). Las fechas y pendientes de abajo pueden estar superados.
>
> **Correcciones (al 2026-05-31):** el freeze "2026-05-20" no aplica; el régimen vigente para este frente (docs/visión, ex-Track B) es **push libre hasta 2026-06-11** y **freeze de código 2026-06-15**. PR #101 ya está en `main`. **DUPLICADO:** el detalle de los temas V-A..V-F vive también en `programa-benjamin-rpi-hardware.md` y en la subcarpeta `auditoria-integral-2026-05-18/` — no reabrir.

**Fase:** 🟢 Fase 1 — push exhaustivo · **T–6 semanas a Incheon** · freeze el 2026-05-20. *(HISTÓRICO — ver banner.)*

Benjamin: este issue junta **lo previo abierto que te toca** + **los hallazgos nuevos de RPi/visión** de la auditoría 2026-05-16. Sos codeowner RPi+hardware y el que tiene mejor acceso al banco, así que además de tus temas propios sos el **gate de validación en banco** de todo el cluster RPi (los fixes de Lucio se mergean con tu check de banco + entrada en `testing/TEST_LOG.md`).

Formato de cada tema: riesgo-si-NO / riesgo-si-SÍ / tiempo / criterio de "hecho".

---

### A) Hallazgos PREVIOS ya con issue abierto (referencia — NO reabrir, trabajarlos desde su issue)

Estos ya están como issue; los listo para que tengas el cluster completo en un solo lugar:

- **#65** `vs.read()` puede devolver `None` → crash visión con cámara desconectada. Fix ~3 líneas. **must.**
- **#73** `serial.Serial` sin timeout → deadlock. Fix 1 parámetro. **must.**
- **#66** `ser.write()` sin clamp → `ValueError` rompe frame loop. Fix helper ~5 líneas. **must.**
- **#64** `cv2.imshow` sin guard HEADLESS → CPU desperdiciado, menos FPS. Fix ~4 líneas (patrón ya en `warmup.py`). **must.**
- **#68** `requirements.txt` sin pinning → reinstalar SD limpia rompe todo pre-mundial. Fix `pip freeze` + pinear. **must** *(ya estabas asignado en #68).*

Tu rol acá: ejecutar #68 vos, y **co-review + banco** de #65/#66/#73/#64 (los toca Lucio).

---

### B) Hallazgos NUEVOS de RPi/visión (auditoría 2026-05-16 — para abrir/triage)

#### TEMA V-A — Frame race condition en `camthreader`
- **Archivo:** `software/raspberry/final_rpi/camthreader.py:32-36`
- **Qué:** `self.grabbed, self.frame = self.stream.read()` sin lock; el main lee `self.frame` concurrente → frames stale o duplicados (no son `None`, el guard de #65 no los detecta).
- **Riesgo si NO:** decisiones de ángulo sobre frame con 2-3 frames de latencia extra → en curva cerrada el ángulo es de la recta anterior → se sale de línea / se pasa rampa.
- **Riesgo si SÍ:** bajo. `threading.Lock()` en `__init__`, adquirir en `update()` y `read()`. ~6 líneas, no cambia interfaz.
- **Tiempo:** ~20 min + banco.
- **Hecho:** PR + banco: `print(id(frame))` 5 s, sin lock hay IDs repetidos; con lock no. Entrada en TEST_LOG.
- **Balde:** must.

#### TEMA V-B — `enhance()` hace doble/triple conversión BGR↔HSV por frame
- **Archivo:** `software/raspberry/final_rpi/Main.py:188-248` (`agcwd`, `anti_flash_preprocess`, `enhance`)
- **Qué:** 2-3 conversiones de color completas por frame sobre 256×256 (anti-flash HSV + agcwd HSV + BGR2RGB del modelo). ~3-7 ms/frame desperdiciados; TFLite ya es el cuello.
- **Riesgo si NO:** FPS de inferencia limitado por conversiones evitables, no por el modelo. `frame_q` se llena antes, capture_thread bloquea.
- **Riesgo si SÍ:** bajo. Fusionar a una sola pasada HSV (flash mask + LUT sobre canal V, una conversión). ~30 líneas, lógica equivalente.
- **Tiempo:** ~45 min + banco (verificar que los colores detectados no cambian).
- **Hecho:** `perf_counter` alrededor de `enhance()` baja de ~8 ms a ~4-5 ms en la Pi; FPS +15-25%. Número en TEST_LOG.
- **Balde:** must (mayor potencial de performance absoluto).

#### TEMA V-C — `frame_q` (maxsize=2) bloquea `capture_thread` bajo throttling térmico
- **Archivo:** `software/raspberry/final_rpi/Main.py:314,449`
- **Qué:** `frame_q.put(frame)` sin `nowait`/timeout → si la inferencia tiene un spike (calor de arena, throttling), la cola se llena en 2 frames y el capturador se congela; al liberar procesa 2 frames viejos.
- **Riesgo si NO:** en competencia con Pi caliente, comandos basados en frames de 200-400 ms de antigüedad justo cerca de la zona de rescate (tracking fino crítico).
- **Riesgo si SÍ:** bajo-medio. Patrón drop-oldest (`put_nowait` + `get_nowait` en `except Full`). ~5 líneas. El `CentroidTracker max_lost=8` ya tolera gaps.
- **Tiempo:** ~15 min + banco.
- **Hecho:** inyectar `sleep(0.15)` en infer_thread y verificar que el main procesa el frame más fresco (no 2 stale). Entrada en TEST_LOG.
- **Balde:** must (lo que el auditor marcó como más importante de visión).

#### TEMA V-D — `agcwd()` arma el LUT con list-comprehension Python (256 iter/frame)
- **Archivo:** `software/raspberry/final_rpi/Main.py:198-199`
- **Qué:** LUT de 256 con `[int(255*(i/255)**(1-w_cdf[i])) for i in range(256)]` en Python puro, cada frame. ~0.5-1 ms/frame evitable.
- **Riesgo si NO:** CPU desperdiciada en hot path; suma al V-B.
- **Riesgo si SÍ:** mínimo. Vectorizar con `np.power(np.arange(256)/255, 1-w_cdf)...`. 1 línea, semántica idéntica (±1 LSB irrelevante).
- **Tiempo:** ~10 min + banco.
- **Hecho:** `timeit` 1000 iter, 3-4× speedup. Entrada en TEST_LOG.
- **Balde:** must (quick win casi sin riesgo).

#### TEMA V-E — `calibration.py` desincroniza los frames mostrados
- **Archivo:** `software/raspberry/final_rpi/calibration.py:29-37`
- **Qué:** 2 `vs.read()` por iteración (el primero se descarta); LAB es del frame N y RGB del N+1. `namedWindow` dentro del loop. El operador calibra color sobre frames distintos.
- **Riesgo si NO:** umbrales de color mal calibrados → falsos +/− de verde/zona → puntos perdidos en competencia.
- **Riesgo si SÍ:** muy bajo. Reordenar el `read()` y sacar `namedWindow` del loop. ~3 líneas.
- **Tiempo:** ~10 min + banco.
- **Hecho:** apuntar a objeto en movimiento lento; ventanas RGB/LAB sincronizadas. Entrada en TEST_LOG.
- **Balde:** must (afecta directamente la calidad de calibración pre-mundial — tu dominio de banco).

#### TEMA V-F — `print(area)` en el hot path del loop de línea
- **Archivo:** `software/raspberry/final_rpi/Main.py:799`
- **Qué:** `print(area)` por cada contorno de plata, en cada frame del estado `linea`. Con piso reflectivo (5-10 contornos de ruido) → hasta ~20 ms I/O bloqueante/frame.
- **Riesgo si NO:** FPS del loop de línea cae justo en piso brillante de estadio (de ~40 Hz a ~20 Hz en el peor caso). Ensucia el journal y dificulta debug real.
- **Riesgo si SÍ:** mínimo. Borrar o poner detrás de flag debug. La telemetría cada 5 s ya cubre.
- **Tiempo:** ~5 min + banco.
- **Hecho:** medir FPS con piso brillante con/sin el print; recuperación 2-8 FPS. Entrada en TEST_LOG.
- **Balde:** must (mejor ratio impacto/esfuerzo de todo el cluster).

---

### Tu prioridad sugerida esta semana *(HISTÓRICO: "antes del freeze 2026-05-20" → al 2026-05-31 el frente docs/visión tiene push libre hasta 2026-06-11, freeze de código 2026-06-15)*

1. **#68** (tuyo) — pinear `requirements.txt` desde la Pi de la última corrida buena.
2. **Banco + co-review** de los fixes de Lucio (#65/#66/#73/#64 + V-A/V-D/V-E/V-F) — sos el gate de validación.
3. **V-B y V-C** — los de mayor potencial de performance; coordinar con Lucio quién los toma, vos validás en banco con medición de FPS antes/después.

Regla de "hecho" transversal: **PR mergeado + 1 corrida de banco que lo valide + 1 línea en `testing/TEST_LOG.md`** (existe gracias al PR #101).

*Auditoría asistida por Claude Code bajo supervisión de @gviollaz. Cluster RPi/hardware extraído del consolidado (ver issue gemelo asignado a @enzzo19 para el panorama de los 3 subsistemas).*

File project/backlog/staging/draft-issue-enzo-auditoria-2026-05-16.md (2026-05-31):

## Consolidado de auditoría 2026-05-16 — input para el triage #91

> **DOCUMENTO HISTÓRICO (2026-05-16).** Estado de proyecto y régimen vigente: ver [`docs/es/ESTADO-ACTUAL-2026-05-31.md`](../../../docs/es/ESTADO-ACTUAL-2026-05-31.md). Las fechas y pendientes de abajo pueden estar superados.
>
> **Correcciones (al 2026-05-31):** este consolidado del 16-may quedó **superado por la auditoría integral 31-may** ([`2026-05-31-informe-coach-auditoria-integral.md`](../../../docs/es/2026-05-31-informe-coach-auditoria-integral.md)) y por PR #129 (fixes B1–B10, OPEN, validar en banco — no mergear a ciegas). Freeze "2026-05-20" no aplica → régimen vigente: firmware/comms gated por Enzo, docs/visión push libre ≤2026-06-11, freeze de código 2026-06-15. **Reinterpretaciones factuales vigentes:** PID/PWM (#121/B1) — los motores son DFRobot FIT0441 con PWM invertido, `255 - _pwmVal` es correcto a nivel HW; el problema es el **lazo** (PID DIRECT + ki dominante + kp=0), es rediseño, NO un fix de signo. Clases YOLO (#120/B3) — **NO están invertidas** (coinciden con `metadata.yaml`); lo invertido eran nombres de sub-estados de depósito.

**Fase:** 🟢 Fase 1 — push exhaustivo · **T–6 semanas a Incheon** · freeze el 2026-05-20 (3-4 días). *(HISTÓRICO — ver banner.)*
Auditoría integral de los 3 subsistemas (Teensy firmware / RPi visión / comms) sobre branch `feature/initialize-testing-log` (commit `c42e535`). Deduplicado contra issues #4–#102 y `AUDIT-ACTION-PLAN.md`.

**Para Enzo:** esto es el insumo para cerrar el triage del #91 (vence). Decidir baldes (must/should/post-mundial) y qué se congela el 2026-05-20.

---

### 🔴 ALERTA P0 — confirmado (no es finding nuevo, es estado de #59/#60/#61/#62)

Los timeouts de los issues **#59 / #60 / #61 / #62 están REVERTIDOS** en el código actual.

- `5bac4a5 feat(teensy): timeouts implementados` los implementó.
- `cead75e fix(teensy): error de libreria claw.cpp` borró 181 líneas (incl. `priority_fix_flags.h`).
- Ningún commit posterior los restauró.

El equipo opera creyendo que están resueltos y **no lo están**. Recomendación: re-aplicar incremental (issue por issue) tras arreglar el error de `claw.cpp` que forzó el revert. **Prioridad #1 de Laureano antes del freeze.**

---

### Quick-wins de CONFIABILIDAD (bajo riesgo · alto potencial · entran antes del 05-20)

| Tema | Subsist | Archivo | Fix | Riesgo fix | Por qué alto impacto |
|---|---|---|---|---|---|
| **T-A** `get_color()` sin timeout | control | `main.cpp:336` | 3 líneas (guard `millis()`) | Muy bajo | Se llama cada iteración del loop de línea. I2C flojo por vibración/rampa → freeze permanente → LoP sin recuperación |
| **T-B** `taskDone` nunca vuelve a `false` | control | `main.cpp:59` | 1 línea (init `true`) | Bajo | Si arranca sin ritual switch-off, no despacha acciones (ignora verde/obstáculo). El juez puede no dar tiempo al ritual |
| **V-A** Frame race en `camthreader` | visión | `camthreader.py:32` | `threading.Lock`, 6 líneas | Bajo | `grabbed,frame` sin lock → decisiones de ángulo sobre frame stale → se pasa rampa/curva |
| **V-E** `calibration.py` desincronizada | visión | `calibration.py:29` | 3 líneas | Muy bajo | Operador calibra color viendo LAB y RGB de frames distintos → umbrales mal → falsos +/− de verde |
| **C-A** Test comms 57600 vs prod 115200 | comms | `test/comms/serialReceive.cpp:21` | 1 número | Muy bajo | La única herramienta de diagnóstico de comms da resultados falsos — agujero ciego en semanas de banco |

### Quick-wins de PERFORMANCE (bajo riesgo · alto potencial)

| Tema | Subsist | Archivo | Fix | Riesgo fix | Ganancia estimada |
|---|---|---|---|---|---|
| **V-F** `print(area)` en hot path de línea | visión | `Main.py:799` | borrar / flag debug | Mínimo | `print` por contorno por frame, ~20 ms I/O. +5-15% FPS en piso reflectivo. *Mejor ratio de todos* |
| **V-D** `agcwd()` LUT con list-comprehension | visión | `Main.py:198` | 1 línea (vectorizar) | Mínimo | 256 iter Python/frame × 35 fps. Sin cambio de semántica |
| **V-B** `enhance()` doble conversión BGR↔HSV | visión | `Main.py:188-248` | refactor ~30 líneas | Bajo (banco) | 2-3 conversiones color/frame. +15-25% FPS de inferencia — mayor potencial absoluto |
| **V-C** `frame_q` bloquea `capture_thread` | visión | `Main.py:314,449` | drop-oldest, ~5 líneas | Bajo-medio | Throttling térmico → productor colgado → frames 200-400 ms viejos en rescate |
| **T-C** `delay(10)` por iter en `runDistance` | control | `main.cpp:551,575` | quitar/bajar a 1 ms | Bajo | PID limitado a 100 Hz → menos precisión en avances de 5-8 cm de zona de rescate |

### NO son quick-win (banco con cuidado o post-freeze — honestidad de coach)

| Tema | Subsist | Por qué medio/alto riesgo |
|---|---|---|
| FSM rescate llama `runDistance/runTime` bloqueantes (relac. #59) | control | Refactor a sub-FSM con `millis()`. Alto payoff pero toca lógica de rescate validada |
| `serialEvent5` desfase post-maniobra → `speed=254` aberrante (relac. #70) | comms | Refactor parser, afecta 5 call-sites. Medio-alto |
| `Serial5.write(255)` colisiona con `SYNC_SPEED` (5 sitios) | comms | Switch accidental → RPi en `'esperando'` infinito. Fix bilateral |
| Doble-pick `green_state==6/7` con `if` sin `else if` | comms/control | Re-detección → secuencia pinza 2× → `ball_counter` falso → depósito falla |
| `runTime/runDistance` consumen serial sin parsear (relac. #63) | comms | Comandos de pinza en rescate se pierden. Cuidar la parada por switch |

---

### Verificación útil (riesgo descartado)

Los auditores confirmaron que los **rangos del payload serial NO colisionan con sync bytes** en producción (`speed` 0-40, `angle+90` 0-180, todos < 252). Un riesgo que se puede tachar de la lista.

### Acciones sugeridas para el triage #91

1. Mover los 10 quick-wins a `must-ship-incheon` (caben antes del freeze, bajo riesgo).
2. Re-aplicar timeouts #59/#60/#61/#62 → prioridad #1 Laureano.
3. Los 5 medio-riesgo → evaluar uno por uno: ¿entra antes del 05-20 con banco, o `post-mundial`?
4. Cluster RPi/hardware detallado → ver el issue de Benjamin (creado en paralelo a este).

*Auditoría asistida por Claude Code bajo supervisión de @gviollaz. Hallazgos en formato TEMA A ANALIZAR (riesgo-si-no / riesgo-si-sí / tiempo).*

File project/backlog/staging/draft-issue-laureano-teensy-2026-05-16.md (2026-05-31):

## Cluster Teensy / firmware — para Laureano (Laureano Monteros, `Laumonteros`, codeowner firmware)

> Nota de nombres: **Laureano = Laureano Monteros = `Laumonteros`** — misma persona, el del firmware Teensy.

> **DOCUMENTO HISTÓRICO (2026-05-16).** Estado de proyecto y régimen vigente: ver [`docs/es/ESTADO-ACTUAL-2026-05-31.md`](../../../docs/es/ESTADO-ACTUAL-2026-05-31.md). Las fechas y pendientes de abajo pueden estar superados.
>
> **Correcciones (al 2026-05-31):** el freeze "2026-05-20" no aplica → firmware/comms ya entra por **gate de Enzo** (ventana de push vencida; freeze de código 2026-06-15). Buena parte de estos fixes hoy viven (total o parcial) en **PR #129 (OPEN) — validar en banco, no mergear a ciegas.** Si algún ítem toca el **lazo de control / PID**, aplica la reinterpretación **#121/B1**: motores DFRobot FIT0441 con PWM invertido (`255 - _pwmVal` es correcto a nivel HW); el problema es el lazo (PID DIRECT + ki dominante + kp=0), es rediseño, NO un fix de signo. **DUPLICADO:** detalle ampliado en `programa-laureano-teensy-resiliencia.md`.

**Fase:** 🟢 Fase 1 — push exhaustivo · **T–6 semanas a Incheon** · freeze el 2026-05-20 (3-4 días). *(HISTÓRICO — ver banner.)*

Laureano: este issue junta tu frente de firmware Teensy — lo previo abierto + los hallazgos nuevos de la auditoría 2026-05-16 (branch `feature/initialize-testing-log`, commit `c42e535`). Formato de cada tema: riesgo-si-NO / riesgo-si-SÍ / tiempo / criterio de "hecho". Ver panorama completo en #103.

---

### 🔴 PRIORIDAD #1 — Re-aplicar los timeouts (CONFIRMADO revertidos)

Los issues **#59 / #60 / #61 / #62** tienen su fix **revertido en el código actual**:
- `5bac4a5 feat(teensy): timeouts implementados` los implementó.
- `cead75e fix(teensy): error de libreria claw.cpp` borró 181 líneas (incl. `priority_fix_flags.h`).
- Ningún commit posterior los restauró.

- **Riesgo si NO:** el equipo cree que están resueltos. En competencia, cualquiera de esas causas (encoder que no llega al target, sensor color colgado, fallo de init) **cuelga el robot sin recuperación** → LoP repetido (−5 c/u, tope −20).
- **Riesgo si SÍ:** medio — hay que primero entender el error de `claw.cpp` que forzó el revert, después re-aplicar incremental (un issue a la vez, con banco entre cada uno). NO re-aplicar los 181 líneas de golpe.
- **Tiempo:** ~3-4 h (diagnóstico claw.cpp + re-aplicación incremental + banco por cada uno).
- **Hecho:** #59/#60/#61/#62 con su fix vivo en `main`, cada uno con corrida de banco que reproduce el fallo y confirma el timeout + línea en `testing/TEST_LOG.md`.
- **Balde:** must — lo primero de la semana.

---

### A) Hallazgos PREVIOS de control ya con issue abierto (referencia — trabajar desde su issue)

- **#57** [P0] Zona rescate: ambas ramas rotan −90 en busca de pared. **must.**
- **#58** [P1] `case 12` cae al `case 14` por falta de `break` → `runAngle(180)` espurio. Fix: agregar `break;` entre líneas 1113-1115 (ojo: el `break` de la línea 1112 está dentro del `while` interno, no del `switch`). **must.**
- **#59/#60/#61/#62** — ver PRIORIDAD #1 arriba.
- **#67** [P2] `Moto::pulseCount` sin init en constructor → valor basura antes del primer reset. Fix 1 línea. **should.**

---

### B) Hallazgos NUEVOS de firmware (auditoría 2026-05-16)

#### TEMA T-A — `get_color()` bloquea sin timeout
- **Archivo:** `software/teensy/firmware/src/main.cpp:336-339`
- **Qué:** `while (!apds.colorDataReady()) { delay(5); }` sin timeout. Se llama **cada iteración** del loop de línea (main.cpp:887) y en evasión de obstáculo (951, 966). (Distinto del while que cubre #61.)
- **Riesgo si NO:** I2C flojo por vibración/rampa → `colorDataReady()` nunca devuelve true → **freeze permanente** del robot, sin recuperación.
- **Riesgo si SÍ:** muy bajo. Guardar `millis()` antes del while + `if ((millis()-waitStart)>50) return "Desconocido";`. Cambio atómico de 3 líneas en una función.
- **Tiempo:** ~10 min + 15 min banco.
- **Hecho:** desconectar SDA del APDS9960 con el robot corriendo → debe seguir avanzando en "Desconocido", no congelarse. Línea en TEST_LOG.
- **Balde:** must (confiabilidad alta, riesgo mínimo).

#### TEMA T-B — `taskDone` nunca se resetea a `false`
- **Archivo:** `software/teensy/firmware/src/main.cpp:59, 821, 900`
- **Qué:** `taskDone` sólo pasa a `true` en el handler de switch-off (821) y es la única condición que habilita el dispatch de acciones (900). Si el robot arranca sin pasar por el ritual switch-off → `taskDone=false` → **nunca entra al switch de acciones** (solo linetrack, ignora verde/obstáculo).
- **Riesgo si NO:** comportamiento errático según el orden de encendido. En competencia el juez puede no dar tiempo al ritual switch-off/on → el robot ignora todos los comandos de verde.
- **Riesgo si SÍ:** bajo-medio. Inicializar `taskDone=true` (línea 59) o setearlo en el bloque `startUp`. Verificar en banco que no rompe el ritual de arranque.
- **Tiempo:** ~15 min + 20 min banco.
- **Hecho:** encender y activar switch directamente sin ciclo switch-off previo → responde a comandos de verde. Línea en TEST_LOG.
- **Balde:** must (confiabilidad media, clase entera de bug errático).

#### TEMA T-C — `delay(10)` por iteración en `runDistance()`
- **Archivo:** `software/teensy/firmware/src/main.cpp:551, 575`
- **Qué:** `delay(10)` fijo por iteración en ambos loops de `runDistance` → control loop limitado a 100 Hz; el PID de posición responde a la mitad de lo que el hardware da. Durante esos 10 ms no se lee el switch ni `claw.update()`.
- **Riesgo si NO:** menos precisión en avances de 5-8 cm de la zona de rescate (recogida de pelota, posicionamiento de depósito) — donde cada cm cuesta puntos.
- **Riesgo si SÍ:** bajo. Quitar el `delay(10)` o bajarlo a 1 ms; reintegrar el timeout de #60 al mismo tiempo.
- **Tiempo:** ~20 min + 30 min banco (medir error a 5/10/20 cm con y sin delay).
- **Hecho:** error promedio de 5 corridas a 5/10/20 cm mejora medible. Línea en TEST_LOG.
- **Balde:** should (performance media; combinar con re-aplicación de timeout #60).

#### TEMA T-D — `runTime()` usa `unsigned long long` vs `millis()` `unsigned long` (menor)
- **Archivo:** `software/teensy/firmware/src/main.cpp:411-413`
- **Qué:** tipos mezclados; en Cortex-M7 los 64 bits no son atómicos (2 instrucciones de 32). Riesgo real bajo (en una competencia de días no hay overflow de 49 días; `startTime` se escribe una vez).
- **Riesgo si NO:** mínimo en práctica; queda como bug latente para futuros refactors.
- **Riesgo si SÍ:** muy bajo. Cambiar a `unsigned long` en 2 lugares; sin cambio observable.
- **Tiempo:** ~5 min + compilar con `-Wall -Wconversion`.
- **Hecho:** desaparecen los warnings de conversión implícita.
- **Balde:** nice-to-have (solo si sobra tiempo antes del freeze).

---

### NO quick-win de tu dominio (banco con cuidado o post-freeze)

- **FSM rescate llama `runDistance/runTime` bloqueantes** (relac. #59): `actualizarRescate()` se diseñó no-bloqueante pero `RESCATE_*_STEP4/STEP8` llaman a funciones bloqueantes que congelan el main loop por segundos (la garra no actualiza mientras avanza). Refactor a sub-FSM con `millis()`, 2-3 estados nuevos por secuencia. Alto payoff, **riesgo medio** — banco intensivo, evaluar si entra antes del 05-20 o `post-mundial`.

---

### Tu prioridad sugerida esta semana *(HISTÓRICO: "antes del freeze 2026-05-20" → al 2026-05-31 firmware ya entra por gate de Enzo; freeze de código 2026-06-15)*

1. **Re-aplicar timeouts #59/#60/#61/#62** (PRIORIDAD #1 — diagnosticar claw.cpp primero, re-aplicar incremental).
2. **T-A `get_color()` timeout** + **T-B `taskDone`** + **#58 `break`** — 3 quick-wins de confiabilidad de bajo riesgo.
3. **T-C `delay(10)`** combinado con la re-aplicación del timeout de #60.
4. T-D y #67 si sobra tiempo (nice).

Regla de "hecho" transversal: **PR mergeado + 1 corrida de banco que lo valide + 1 línea en `testing/TEST_LOG.md`** (existe por PR #101). Banco obligatorio antes de mergear firmware (regla del repo).

*Auditoría asistida por Claude Code bajo supervisión de @gviollaz. Panorama de los 3 subsistemas en #103; cluster RPi/hardware en #104.*

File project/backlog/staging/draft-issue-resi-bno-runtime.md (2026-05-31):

## Resiliencia R-T06 — BNO055 sin detección de fallo en runtime ni re-init automático (heading basura silencioso)

> **DOCUMENTO HISTÓRICO (2026-05-18).** Estado de proyecto y régimen vigente: ver [`docs/es/ESTADO-ACTUAL-2026-05-31.md`](../../../docs/es/ESTADO-ACTUAL-2026-05-31.md). Las fechas y pendientes de abajo pueden estar superados.
>
> **Correcciones (al 2026-05-31):** régimen "Track A push libre ≤2026-05-26" SUPERADO → firmware/comms ya entra por **gate de Enzo** (ventana de push vencida). **DUPLICADO:** gemelo del tema #109 en `programa-laureano-teensy-resiliencia.md`. Estado real de los fixes de firmware: en PR #129 (OPEN, validar en banco).

**Origen:** auditoría de resiliencia 2026-05-18 (commit `c42e535`). Track A (control/firmware). Severidad: **CRÍTICA**.

### Modo de falla
`leer_yaw()`, `leer_pitch()`, `runAngle()`, `avance_recto()` llaman `bno.getEvent()` **sin verificar el retorno** (`software/teensy/firmware/src/main.cpp:436-449, 611-622`). Si el BNO055 pierde I2C en runtime (golpe, ruido EMI de motores en rampa, conector flojo), la lib Adafruit devuelve `0.0` o el último valor cacheado. El robot navega con heading basura **sin saberlo** — falla silenciosa, la peor clase en competencia (no se cuelga, hace lo incorrecto). `resetear_bno()` existe pero **nunca se invoca automáticamente** desde el loop.

### ¿Se recupera solo HOY?
**NO.** No hay verificación del retorno de `getEvent()`, no hay flag `bno_ok`, no hay detección de "heading congelado", `resetear_bno()` solo sería manual.

### Qué falta para self-healing
1. Verificar el `bool` que retorna `bno.getEvent()`; si falla → `bno_ok = false`.
2. Detección de "heading congelado": mismo valor por >500 ms con motores girando → sospechar sensor muerto.
3. Mientras `!bno_ok`: llamar `resetear_bno()` (con timeout, sin el `while(1)` actual), y degradar `runAngle()` a giro por tiempo en vez de converger por ángulo.

### Test plan (banco)
Con el robot girando (`runAngle`), desconectar SDA del BNO055 en caliente → debe detectar el fallo, intentar re-init, y completar el giro por tiempo (no girar infinito ni navegar con heading 0).

**Régimen:** ~~Track A (firmware) — push libre ≤2026-05-26~~ → **al 2026-05-31: firmware/comms con ventana de push vencida, entra por gate de Enzo.** **Asignar:** @Laumonteros @gviollaz.

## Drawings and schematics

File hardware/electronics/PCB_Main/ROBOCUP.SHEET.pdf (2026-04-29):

# +12VCC +¹²VCC

# GNDGND

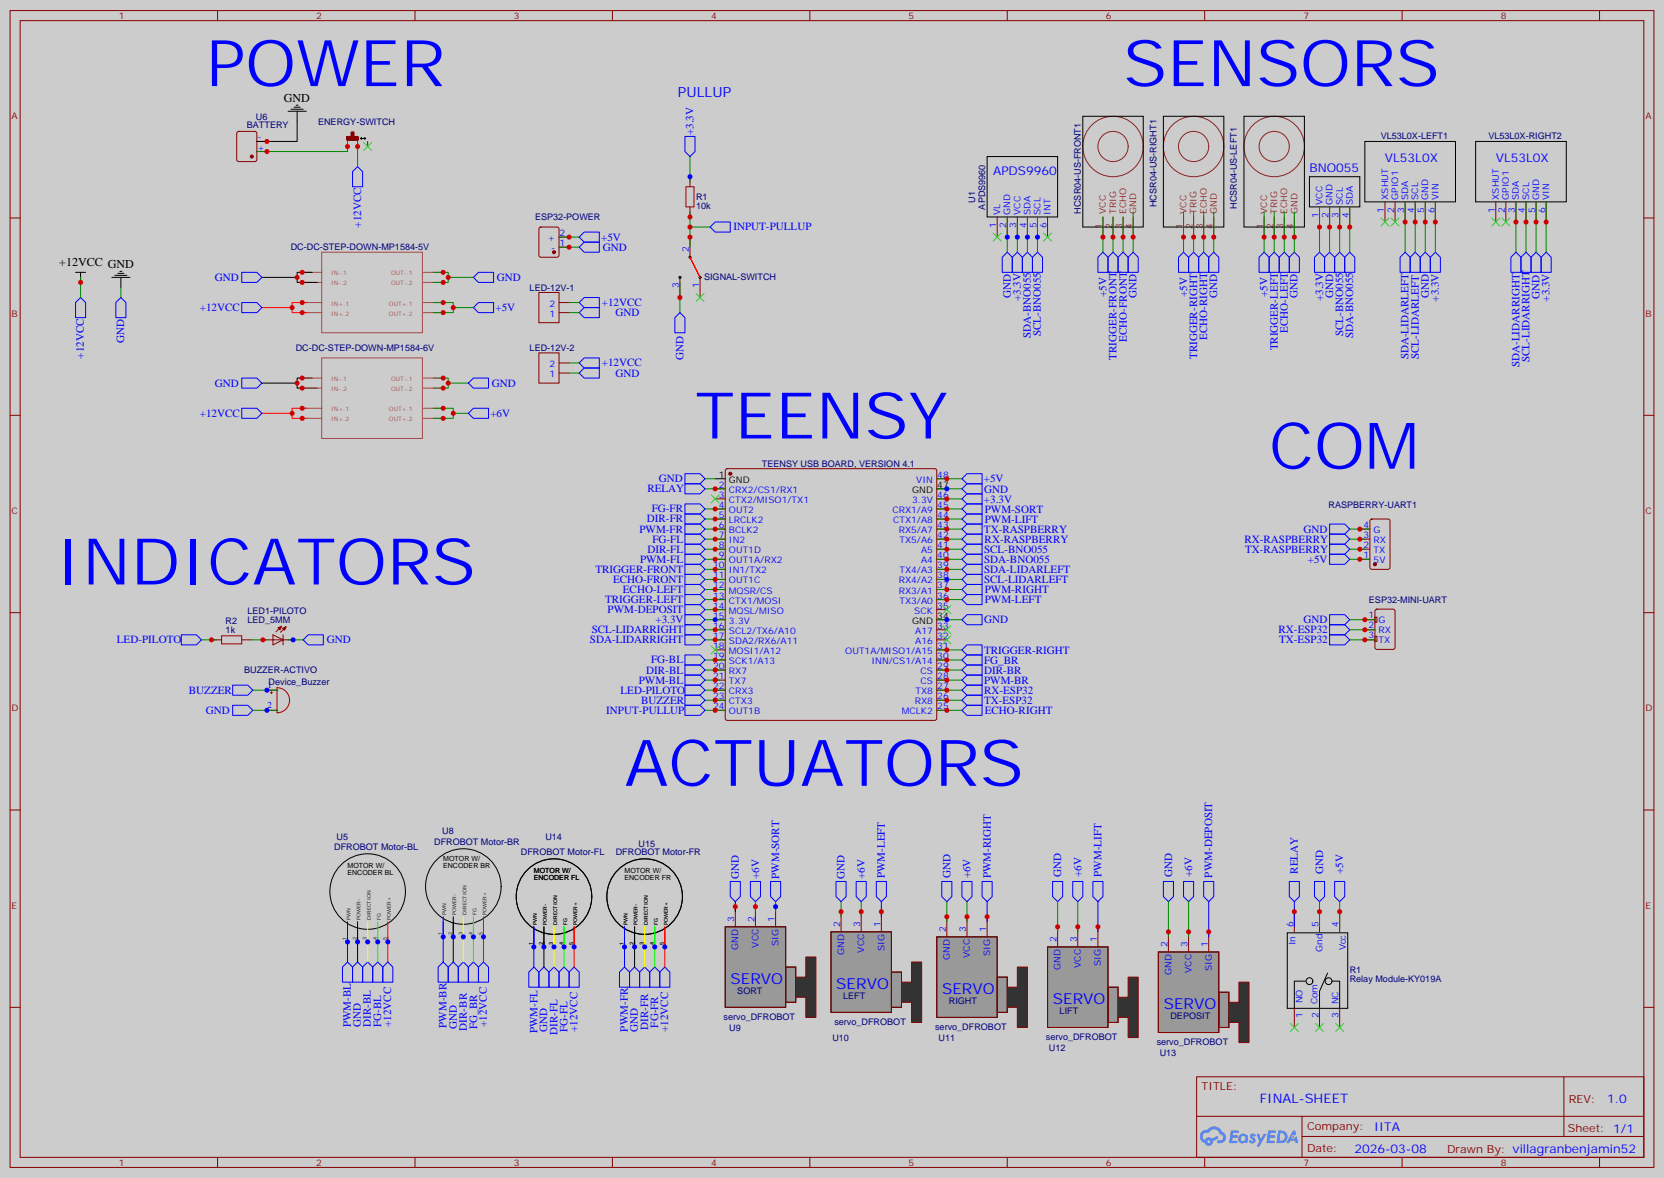
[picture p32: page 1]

DC-DC-STEP-DOWN-MP1584-5V

DC-DC-STEP-DOWN-MP1584-6V

TEENSY USB BOARD, VERSION 4.1

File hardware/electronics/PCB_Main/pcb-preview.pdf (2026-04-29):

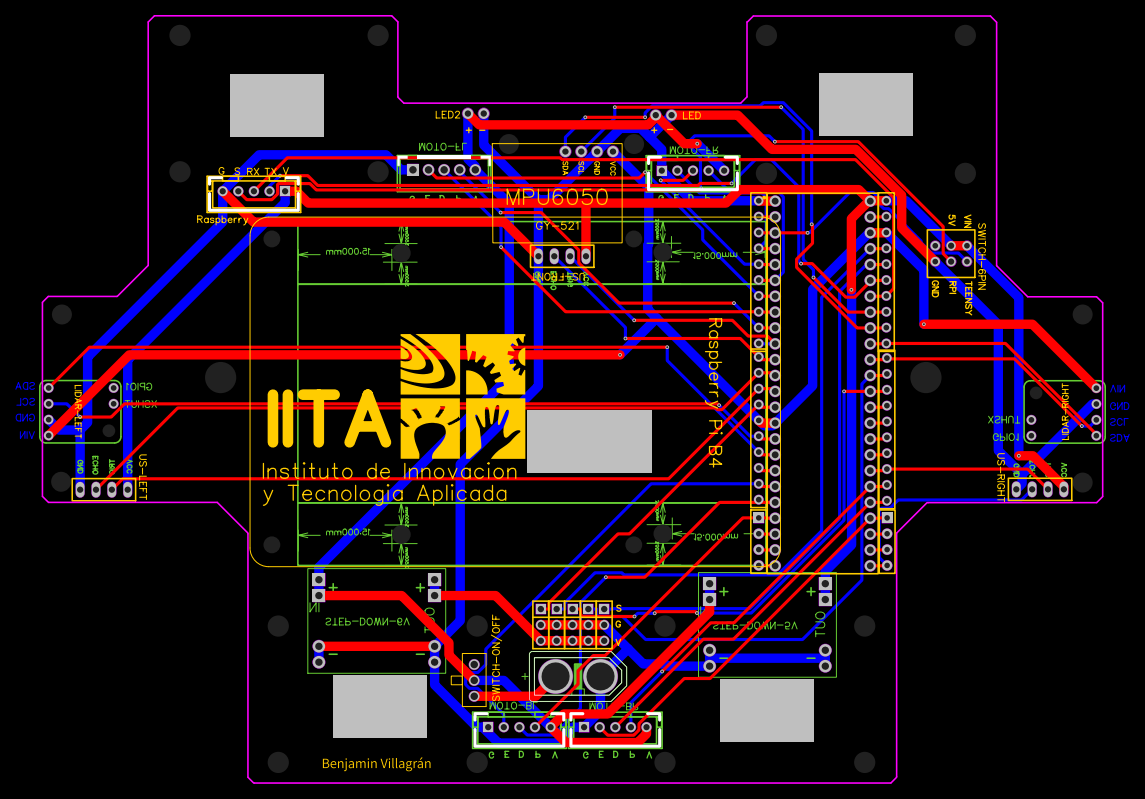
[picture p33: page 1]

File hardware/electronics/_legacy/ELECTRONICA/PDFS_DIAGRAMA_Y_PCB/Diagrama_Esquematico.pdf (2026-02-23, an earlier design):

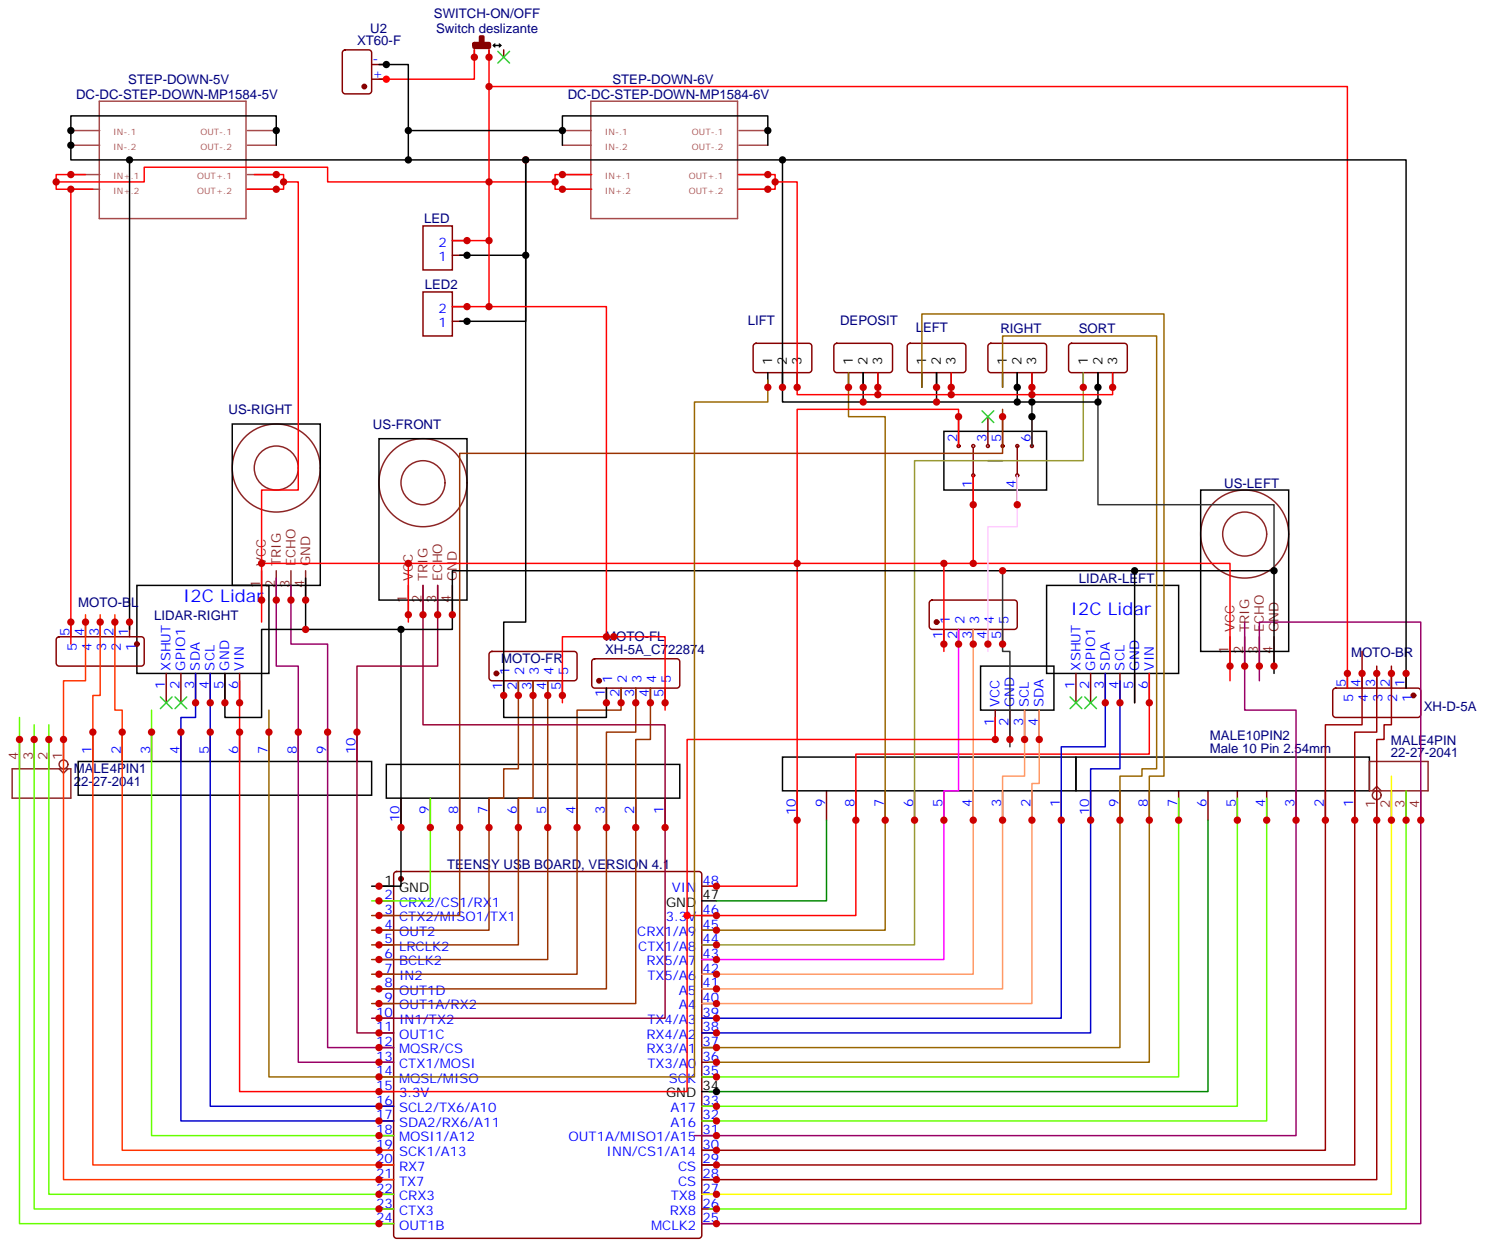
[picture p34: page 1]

STEP-DOWN-5V
DC-DC-STEP-DOWN-MP1584-5V

STEP-DOWN-6V
DC-DC-STEP-DOWN-MP1584-6V

IN-.1 OUT-.1 IN-.2 OUT-.2

IN+.1 OUT+.1 IN+.2 OUT+.2

TEENSY USB BOARD, VERSION 4.1


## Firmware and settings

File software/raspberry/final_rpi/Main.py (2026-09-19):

import cv2
from software.raspberry.final_rpi.mainenviar import *
import numpy as np
import math
import time
import serial
import sys
import os
import threading
import queue
# Registro por frame del lado de la vision. Apagado salvo que exista la
# variable de entorno TLM_VISION; sin ella no abre archivo ni cuesta nada.
#
# EL IMPORT VA PROTEGIDO, y no es paranoia. telemetria_vision.py promete en su
# docstring que NUNCA levanta una excepcion hacia el lazo de vision, y sus
# METODOS lo cumplen. Pero el import no estaba cubierto: lo que corre en la
# Raspberry es un archivo suelto del Desktop, asi que alcanzaba con copiar
# Main.py y olvidarse de copiar telemetria_vision.py al lado para que la VISION
# NO ARRANCARA. Un registro no puede voltear una corrida: si no esta, se usa un
# objeto nulo y el robot corre igual, sin telemetria de vision y sin enterarse.
try:
    from telemetria_vision import tlmv
except Exception as _e:                      # ImportError, y tambien cualquier otra
    print("[TLM-VISION] no se pudo importar (%s): sigo SIN registro de vision" % _e)

    class _TlmvNulo(object):
        activa = False

        def frame(self, **k):
            pass

        def cerrar(self):
            pass

    tlmv = _TlmvNulo()

# Vision de linea nueva. MISMO CONTRATO que telemetria_vision: apagada salvo que
# exista la variable de entorno VISION_LINEA, import protegido, y si algo falla
# se apaga sola y se sigue con la vision vieja. Sin la variable no importa nada
# pesado y no cuesta un microsegundo.
#     VISION_LINEA=camino python3 Main.py    candidata + CAMINO + MONO
#     VISION_LINEA=v1     python3 Main.py    POI sobre contorno
#     python3 Main.py                        vision vieja, sin cambios
try:
    import vision_linea
except Exception as _e:
    print("[VISION-LINEA] no se pudo importar (%s): sigo con la vision vieja" % _e)

    class _VisionNula(object):
        ACTIVA = False

        @staticmethod
        def angulo(_f):
            return None

        @staticmethod
        def ultimo():
            return {}

    vision_linea = _VisionNula()

HEADLESS = os.environ.get("DISPLAY") is None
DEBUG_VIEW = os.environ.get("DEBUG_VIEW") == "1"
SHOW_DEBUG_WINDOWS = (not HEADLESS) or DEBUG_VIEW
ENABLE_CX_BLACK_GUARD = True

# PROTOCOLO RPi -> Teensy
# Frame: [0xFF, speed, 0xFE, angle, 0xFD, green_state, 0xFC, silver_line]
#
# CONTRATO DE RANGOS:
# speed:       [0, 100]
# angle:       [0, 180]   # se envia como angle + 90
# green_state: 0..20
# silver_line: 0 o 1
#
# Los payloads NO deben colisionar con los sync bytes 0xFC..0xFF.

SYNC_SPEED = 0xFF
SYNC_ANGLE = 0xFE
SYNC_GREEN_STATE = 0xFD
SYNC_SILVER_LINE = 0xFC

TEENSY_BOOT = b'\xfa'
TEENSY_READY = b'\xf9'
TEENSY_RESCATE_DONE = b'\xf8'
TEENSY_STOP = b'\xff'
TEENSY_RESCATE = b'\xf1'     # 241 = iniciar modo rescate
TEENSY_EVACUACION = b'\xf7'  # 247 = termino rescate, iniciar evacuacion
SERIAL_TIMEOUT_S = 0.05
# `flush()` en el hot path: ver send_frame(). Por defecto NO se llama.
SERIAL_FLUSH = os.environ.get("SERIAL_FLUSH") == "1"
FRAME_NONE_RETRY_SLEEP_S = 0.01
FRAME_NONE_RESTART_THRESHOLD = 30
TELEMETRY_INTERVAL_S = 5.0

# ---- SWITCH PRINCIPAL ----
# True  -> Zero-DCE en det + AGCWD en intermedios  (Pi 5,  ~20 FPS)
# False -> AGCWD en todos los frames               (Pi 4B, ~35 FPS)
USE_ZERODCE  = False
ZERODCE_PATH = "/home/pi/Downloads/AI_enhance/dcenet_int8.tflite"
ZERODCE_GAIN = 1.65
# --------------------------

debugOriginal = False
debugBlack = True
debugGreen = True
debugBlue = False
debugHori = False
record = True
noise_blob_threshold = 16
min_square_size = 550
min_line_size = 50000
line_lost_search_speed = 12
line_lost_search_angle = 65
fixed_angle_value = 0
fixed_angle_active = False
fixed_angle_start_time = 0
estado = 'esperando'
frames_sent = 0
last_tx_telemetry = time.monotonic()

vs = WebcamVideoStream(src=0).start()
ser = serial.Serial('/dev/serial0', 115200, timeout=SERIAL_TIMEOUT_S, write_timeout=SERIAL_TIMEOUT_S)
lower_black   = np.array([0, 0, 0])
upper_black   = np.array([90, 90, 90])

lower_green = np.array([70, 85, 138])  # lab
upper_green = np.array([104, 102, 158])
lower_silver_hsv = np.array([79, 16, 46])
upper_silver_hsv = np.array([168, 28, 79])
lower_red1 = np.array([0, 84, 54])  # hsv
upper_red1 = np.array([7, 255, 200])
lower_red2 = np.array([170, 84, 54])  # hsv
upper_red2 = np.array([179, 255, 200])
last_angles   = []

YOLO_IMGSZ  = 256

width, height = 160, 120
print(width, height)

cam_x = width / 2 - 1
cam_y = height - 1

timer_active = False
green_output_duration = 1
green_output_cooldown_duration = 2
green_state_final = 0
timer_start_time = 0
silver_line = False

def clamp_byte(value):
    return max(0, min(255, int(value)))

def send_frame(speed, angle, green_state, silver_line_flag):
    global frames_sent, last_tx_telemetry

    output = bytes([
        SYNC_SPEED, clamp_byte(speed),
        SYNC_ANGLE, clamp_byte(angle + 90),
        SYNC_GREEN_STATE, clamp_byte(green_state),
        SYNC_SILVER_LINE, clamp_byte(int(bool(silver_line_flag))),
    ])
    bytes_written = ser.write(output)
    # ser.flush() BLOQUEA hasta que los 8 bytes salieron del buffer del SO:
    # 8*10/115200 = 0,694 ms por trama, y a 80 Hz eso es 55,6 ms por segundo,
    # el 5,6 % del tiempo del lazo de vision. Y NADIE espera esa garantia: no
    # hay ACK, la Teensy no contesta esta trama, y el SO igual la manda. Lo
    # unico que cambia es que el lazo deja de quedarse mirando como sale.
    #
    # Se deja detras de una variable de entorno por si el sabado aparece algun
    # sintoma raro de serie y hay que descartar esto rapido:
    #     SERIAL_FLUSH=1 python3 Main.py    -> vuelve el comportamiento viejo
    if SERIAL_FLUSH:
        ser.flush()
    #print(f"[TX] bytes_written={bytes_written} raw={output.hex()} speed={speed} angle={angle} gs={green_state} sl={silver_line_flag}")

    frames_sent += 1
    now = time.monotonic()
    if now - last_tx_telemetry >= TELEMETRY_INTERVAL_S:
        print(f"[TLM] frames_sent={frames_sent} estado={estado}")
        last_tx_telemetry = now

    return output

def stop_teensy_safely(reason):
    try:
        print(f"[SAFE-STOP] {reason}: enviando speed=0 al Teensy")
        send_frame(0, 0, 0, 0)
    except Exception as exc:
        print(f"[SAFE-STOP] no se pudo enviar stop: {exc}")

def restart_video_stream():
    global vs

    try:
        vs.stop()
    except Exception:
        pass

    time.sleep(0.1)
    vs = WebcamVideoStream(src=0).start()
    return vs

# Ultimo (seq, edad_ms) que entrego la camara. Globales a proposito: el lazo
# llama a read_frame_with_recovery en varios lados y la telemetria los lee
# despues, sin cambiar la firma de la funcion ni el flujo.
CAM_SEQ = 0
CAM_EDAD_MS = 0.0
CAM_REPETIDOS = 0     # veces que se proceso DOS veces el mismo frame
CAM_SALTEADOS = 0     # frames que la camara entrego y el lazo nunca vio


def read_frame_with_recovery(none_count, context):
    global CAM_SEQ, CAM_EDAD_MS, CAM_REPETIDOS, CAM_SALTEADOS
    try:
        frame, seq, edad = vs.read_meta()
        if seq == CAM_SEQ:
            CAM_REPETIDOS += 1        # el lazo corrio mas rapido que la camara
        elif seq > CAM_SEQ + 1:
            CAM_SALTEADOS += seq - CAM_SEQ - 1
        CAM_SEQ, CAM_EDAD_MS = seq, edad
    except AttributeError:
        # un WebcamVideoStream viejo sin read_meta: el lazo sigue igual
        frame = vs.read()
    if frame is not None:
        return frame, 0

    none_count += 1
    if none_count == 1 or none_count % 10 == 0:
        print(f"[WARN] {context}: frame None ({none_count})")

    if none_count >= FRAME_NONE_RESTART_THRESHOLD:
        print(f"[WARN] {context}: reiniciando VideoStream tras {FRAME_NONE_RESTART_THRESHOLD} frames vacios")
        restart_video_stream()
        none_count = 0

    time.sleep(FRAME_NONE_RETRY_SLEEP_S)
    return None, none_count

def handle_control_byte(data, context="serial"):
    global estado

    if not data:
        return None

    if data == TEENSY_BOOT:
        print(f"[INFO] {context}: Teensy reseteado -> esperando")
        estado = 'esperando'
        return 'boot'

    if data == TEENSY_STOP:
        estado = 'esperando'
        return 'stop'

    if data == TEENSY_READY:
        if estado in ('esperando', 'evacuacion'):
            estado = 'linea'
            return 'linea'
        return 'ready'

    if data == TEENSY_RESCATE:
        print(f"[INFO] {context}: Llego 241 -> entrando a rescate")
        estado = 'rescate'
        return 'rescate'

    if data == TEENSY_RESCATE_DONE:
        if estado == 'rescate':
            estado = 'depositar'
            return 'depositar'
        return 'rescate_done'

    if data == TEENSY_EVACUACION:
        if estado in ('rescate', 'depositar', 'depositar verde'):
            estado = 'evacuacion'
            return 'evacuacion'
        return 'evacuacion_ignored'

    return None

x_com = np.zeros(shape=(height, width))
y_com = np.zeros(shape=(height, width))
for i in range(height):
    for j in range(width):
        x_com[i][j] = (j - cam_x) / (width / 2)
        y_com[i][j] = (cam_y - i) / height

# ---- AGCWD ----
def agcwd(img_bgr, w=0.5):
    hsv = cv2.cvtColor(img_bgr, cv2.COLOR_BGR2HSV)
    v   = hsv[:, :, 2]
    hist = np.bincount(v.ravel(), minlength=256).astype(np.float32)
    hist_min, hist_max = hist.min(), hist.max()
    if hist_max - hist_min < 1e-6:
        return img_bgr
    w_pdf = hist_max * ((hist - hist_min) / (hist_max - hist_min)) ** w
    w_cdf = np.cumsum(w_pdf)
    w_cdf = w_cdf / w_cdf[-1]
    lut = np.array([int(255 * (i / 255.0) ** (1.0 - w_cdf[i]))
                    for i in range(256)], dtype=np.uint8)
    mean_v = float(np.mean(v))
    if mean_v > 120:
        lut = (lut * 0.3 + np.arange(256, dtype=np.float32) * 0.7).astype(np.uint8)
    hsv[:, :, 2] = cv2.LUT(v, lut)
    return cv2.cvtColor(hsv, cv2.COLOR_HSV2BGR)

# ---- inicializar Zero-DCE si hace falta ----
if USE_ZERODCE:
    sys.path.insert(0, '/home/pi/Downloads/AI_enhance')
    from zero_dce import ZeroDCE
    print("Cargando Zero-DCE...")
    _enhancer = ZeroDCE(ZERODCE_PATH, patch_size=(YOLO_IMGSZ, YOLO_IMGSZ), num_threads=2)
    print("Zero-DCE listo.")
ENABLE_ANTIFLASH = True

def anti_flash_preprocess(img_bgr, v_flash=215, s_low=60, compress=0.45):
    hsv = cv2.cvtColor(img_bgr, cv2.COLOR_BGR2HSV)
    h, s, v = cv2.split(hsv)
    s = s.astype(np.float32)
    v = v.astype(np.float32)

    flash_mask = (v >= v_flash) & (s <= s_low)

    if not np.any(flash_mask):
        return img_bgr

    mask_blur = flash_mask.astype(np.uint8) * 255
    mask_blur = cv2.GaussianBlur(mask_blur, (5,5), 0)
    alpha = mask_blur.astype(np.float32) / 255.0

    v = v * (1 - alpha) + (v_flash + (v - v_flash) * compress) * alpha

    hsv[:, :, 1] = s.astype(np.uint8)
    hsv[:, :, 2] = v.astype(np.uint8)
    return cv2.cvtColor(hsv, cv2.COLOR_HSV2BGR)

def enhance(img_bgr, use_zerodce=False):
    if use_zerodce:
        rgb = cv2.cvtColor(img_bgr, cv2.COLOR_BGR2RGB)
        rgb = _enhancer.enhance(rgb, gain=ZERODCE_GAIN)
        out = cv2.cvtColor(rgb, cv2.COLOR_RGB2BGR)
    else:
        out = img_bgr
    if ENABLE_ANTIFLASH:
        out = anti_flash_preprocess(out)
    return agcwd(out)


# ---- Inicializar TFLite global + warmup ----
try:
    from tflite_runtime.interpreter import Interpreter as TFLiteInterpreter
    print("Usando tflite_runtime.interpreter")
except Exception:
    import tensorflow as tf
    TFLiteInterpreter = tf.lite.Interpreter
    print("Usando tensorflow.lite.Interpreter (fallback)")

TFLITE_MODEL_PATH = "/home/iita/Documentos/best (2)_float32.tflite"
NUM_THREADS = 2
try:
    interpreter = TFLiteInterpreter(model_path=TFLITE_MODEL_PATH, num_threads=NUM_THREADS)
except TypeError:
    interpreter = TFLiteInterpreter(model_path=TFLITE_MODEL_PATH)
try:
    interpreter.set_num_threads(NUM_THREADS)
except Exception:
    pass

interpreter.allocate_tensors()
_input_details  = interpreter.get_input_details()[0]
_output_details = interpreter.get_output_details()[0]
print("TFLite input:", _input_details)
print("TFLite output:", _output_details)

print("Realizando warmup del modelo TFLite...")
_dummy = np.zeros((YOLO_IMGSZ, YOLO_IMGSZ, 3), dtype=np.uint8)
if np.issubdtype(_input_details['dtype'], np.floating):
    _dummy_inp = (_dummy.astype(np.float32) / 255.0)[np.newaxis, ...].astype(_input_details['dtype'])
else:
    _dummy_inp = _dummy[np.newaxis, ...].astype(_input_details['dtype'])
interpreter.set_tensor(_input_details['index'], _dummy_inp)
interpreter.invoke()
_ = interpreter.get_tensor(_output_details['index'])
print("Warmup completado.")

def modo_rescate(evac_mode=False):
    global last_target_box, is_stopped, estado, ser

    input_details  = _input_details
    output_details = _output_details

    last_target_box = None
    stop_rescate    = False

    if hasattr(cv2, "legacy") and hasattr(cv2.legacy, "TrackerMOSSE_create"):
        print("Legacy MOSSE disponible")
    else:
        print("Legacy MOSSE NO disponible")
    try:
        tr = cv2.legacy.TrackerMOSSE_create() if hasattr(cv2, "legacy") else cv2.TrackerMOSSE_create()
        print("Creado ok:", type(tr))
    except Exception as e:
        print("fallo:", e)

    os.environ["OMP_NUM_THREADS"] = "2"
    os.environ["MKL_NUM_THREADS"] = "2"

    CLASS_NAMES = ['negro', 'plateado', 'rojo alto', 'verde_alto']
    IMGSZ       = YOLO_IMGSZ
    DETECT_EVERY = 3
    MAX_QUEUE    = 2
    DRAW_EVERY   = 1

    last_target_box      = None
    CENTER_TOLERANCE_PX  = 8
    STOP_WIDTH_RATIO     = 0.25
    STOP_WIDTH_RATIO_BOX = 0.98
    STOP_EVAC = 0.68
    RESUME_WIDTH_RATIO   = 0.18
    is_stopped           = False

    CLASS_THRESH = {
        0: 0.45,
        1: 0.45,
        2: 0.5,
        3: 0.6
    }

    CLASS_COLORS = {
        0: (0, 0, 0),
        1: (192, 192, 192),
        2: (0, 100, 255),
        3: (0, 255, 100)
    }

    def make_mosse():
        return None

    class CentroidTracker:
        def __init__(self, max_lost=8):
            self.next_object_id = 0
            self.objects  = {}
            self.lost     = {}
            self.meta     = {}
            self.max_lost = max_lost

        def register(self, bbox, cls=0, score=0.0):
            oid = self.next_object_id
            self.next_object_id += 1
            self.objects[oid] = bbox
            self.lost[oid]    = 0
            self.meta[oid]    = {'cls': cls, 'score': score}
            return oid

        def deregister(self, oid):
            if oid in self.objects: del self.objects[oid]
            if oid in self.lost:    del self.lost[oid]
            if oid in self.meta:    del self.meta[oid]

        def update(self, detections):
            bboxes = [d['xyxy'] for d in detections]

            if len(bboxes) == 0:
                remove = []
                for oid in list(self.lost.keys()):
                    self.lost[oid] += 1
                    if self.lost[oid] > self.max_lost:
                        remove.append(oid)
                for oid in remove: self.deregister(oid)
                return [{'id': oid, 'bbox': self.objects[oid], **self.meta[oid]}
                        for oid in self.objects]

            if len(self.objects) == 0:
                for d in detections:
                    self.register(d['xyxy'], d['cls'], d['score'])
                return [{'id': oid, 'bbox': self.objects[oid], **self.meta[oid]}
                        for oid in self.objects]

            object_ids    = list(self.objects.keys())
            object_bboxes = [self.objects[oid] for oid in object_ids]

            def centroid(b):
                x1, y1, x2, y2 = b
                return ((x1+x2)//2, (y1+y2)//2)

            obj_centroids = [centroid(b) for b in object_bboxes]
            det_centroids = [centroid(d) for d in bboxes]

            D = []
            for oc in obj_centroids:
                row = []
                for dc in det_centroids:
                    dx = oc[0]-dc[0]; dy = oc[1]-dc[1]
                    row.append(dx*dx + dy*dy)
                D.append(row)

            matched_obj = set()
            matched_det = set()
            assignments = {}
            triples = []
            for i in range(len(D)):
                for j in range(len(D[0])):
                    triples.append((i, j, D[i][j]))
            triples.sort(key=lambda x: x[2])
            for i, j, _ in triples:
                if i in matched_obj or j in matched_det: continue
                matched_obj.add(i); matched_det.add(j); assignments[i] = j

            for i, j in assignments.items():
                oid = object_ids[i]
                self.objects[oid] = bboxes[j]
                self.meta[oid]    = {'cls': detections[j]['cls'], 'score': detections[j]['score']}
                self.lost[oid]    = 0

            for j in range(len(detections)):
                if j not in matched_det:
                    self.register(bboxes[j], detections[j]['cls'], detections[j]['score'])

            for i in range(len(object_ids)):
                if i not in assignments:
                    oid = object_ids[i]
                    self.lost[oid] += 1
                    if self.lost[oid] > self.max_lost:
                        self.deregister(oid)

            return [{'id': oid, 'bbox': self.objects[oid], **self.meta[oid]}
                    for oid in self.objects]

    frame_q    = queue.Queue(MAX_QUEUE)
    result_q   = queue.Queue(MAX_QUEUE)
    stop_event = threading.Event()

    def scale_box(box_xyxy, src_w, src_h, in_w=IMGSZ, in_h=IMGSZ):
        x1, y1, x2, y2 = box_xyxy
        scale_x = src_w / in_w
        scale_y = src_h / in_h
        return int(x1*scale_x), int(y1*scale_y), int(x2*scale_x), int(y2*scale_y)

    def capture_thread():
        none_count = 0
        while not stop_event.is_set():
            frame, none_count = read_frame_with_recovery(none_count, "rescate-capture")
            if frame is None:
                continue
            frame = cv2.rotate(frame, cv2.ROTATE_180)
            frame_q.put(frame)
        frame_q.put(None)

    def infer_thread():
        frame_idx = 0
        while True:
            try:
                frame = frame_q.get()
                if frame is None:
                    result_q.put(None)
                    break

                h, w  = frame.shape[:2]
                small = cv2.resize(frame, (IMGSZ, IMGSZ))

                if frame_idx % DETECT_EVERY == 0:
                    small = enhance(small, use_zerodce=USE_ZERODCE)
                else:
                    if ENABLE_ANTIFLASH:
                        small = anti_flash_preprocess(small)
                    small = agcwd(small)
                enhanced_frame = cv2.resize(small, (w, h))

                if frame_idx % DETECT_EVERY == 0:
                    img = cv2.cvtColor(small, cv2.COLOR_BGR2RGB)
                    if np.issubdtype(input_details['dtype'], np.floating):
                        inp = (img.astype(np.float32) / 255.0)[np.newaxis, ...].astype(input_details['dtype'])
                    else:
                        inp = img[np.newaxis, ...].astype(input_details['dtype'])

                    interpreter.set_tensor(input_details['index'], inp)
                    interpreter.invoke()
                    out = interpreter.get_tensor(output_details['index'])[0]

                    detections = []
                    for det in out:
                        x1, y1, x2, y2, score, cls_raw = det
                        score  = float(score)
                        cls_id = int(round(float(cls_raw)))
                        if score < CLASS_THRESH.get(cls_id, 0.5):
                            continue
                        x1 *= IMGSZ; y1 *= IMGSZ; x2 *= IMGSZ; y2 *= IMGSZ
                        sx1, sy1, sx2, sy2 = scale_box((x1, y1, x2, y2), w, h, IMGSZ, IMGSZ)
                        if estado == "rescate":
                            if cls_id in (2, 3): continue
                        if estado == "depositar":
                            if cls_id in (0, 1, 2): continue
                        if estado == "depositar verde":
                            if cls_id in (0, 1, 3): continue
                        if evac_mode:
                            if cls_id in (0, 1): continue  # ignorar pelotas, solo dejar zonas 2 y 3
                        detections.append({'xyxy': (sx1, sy1, sx2, sy2), 'score': score, 'cls': cls_id})

                    result_q.put(('det', enhanced_frame, detections))
                else:
                    result_q.put(('no_det', enhanced_frame, None))

                frame_idx += 1
            except Exception as exc:
                print(f"[ERROR] infer_thread: {exc}")
                stop_event.set()
                result_q.put(None)
                break

    def select_target_from_list(boxes, estado):
        targets = []
        if estado == 'rescate':
            for d in boxes:
                if d['cls'] in (0, 1): targets.append(d)
        if estado == 'depositar':
            for d in boxes:
                if d['cls'] in (3,): targets.append(d)
        if estado == 'depositar verde':
            for d in boxes:
                if d['cls'] in (2,): targets.append(d)
        if estado == 'evacuacion':
            for d in boxes:
                if d['cls'] in (2, 3): targets.append(d)
        if not targets:
            return None
        return targets[0]
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

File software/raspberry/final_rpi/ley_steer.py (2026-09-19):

# -*- coding: utf-8 -*-
"""
LEY DE STEER - separar POSICION de RUMBO. Defecto 3.5.1 del traspaso.

QUE ES Y QUE NO ES, ANTES QUE NADA
----------------------------------
Esto es un controlador EXPERIMENTAL INSPIRADO EN LA ESTRUCTURA DE STANLEY. No
es el Stanley de Thrun et al. y la demostracion de convergencia de ese paper NO
aplica aca. Las cuatro diferencias, todas reales (auditoria de ChatGPT, 25-ago):

  * el cross-track de Stanley se define desde el EJE DELANTERO respecto del
    punto mas cercano de la trayectoria; el de aca se mide en la fila mas baja
    de la imagen (ver la nota de `d_eje` mas abajo);
  * `v` de Stanley es la velocidad longitudinal FISICA; aca es el factor
    relativo [0,55 , 1,0] que la vision pide, y la Teensy lo vuelve a
    transformar con su PID, el pivote y el patinaje;
  * Stanley se demuestra sobre un modelo BICYCLE; este robot es skid-steer de
    4 ruedas fijas;
  * Stanley lleva coeficiente 1 sobre `psi`; aca toda la expresion se escala
    por `g`.

Lo que la estructura de Stanley aporta, y es lo unico que se reclama: DOS
terminos con ganancias separadas, y el de posicion dividido por la velocidad.
Nada mas.

Para este problema exacto -camara fija, camino visible, robot no holonomico- la
referencia mas cercana es el visual servoing de Cherubini, Chaumette y Oriolo,
que usa el primer punto visible del camino y su tangente. Vale mirarlo, y NO se
lo esta implementando aca.

QUE ARREGLA
-----------
La ley de produccion es un solo numero:

    steer = -90 * (x_target - CENTER) / (W/2)

y `x_target` se corre por DOS causas fisicamente distintas:

    e     el robot esta corrido de la cinta        -> error de POSICION
    psi   la cinta DOBLA adelante                  -> error de RUMBO

Medido (`posicion_vs_rumbo.py`): steer = -1,011*e -0,758*psi, R2 0,82, con el
reparto de varianza 47,8 / 52,2. Mitad y mitad, POR EL MISMO NUMERO, con UNA
sola ganancia, y la ley nunca ve la velocidad.

Stanley (Snider CMU-RI-TR-09-08) los separa:

    delta = psi + arctan(k*e / v)

El termino de posicion SE DIVIDE POR LA VELOCIDAD; el de rumbo no. A mas
velocidad, menos angulo por el mismo corrimiento; a menos velocidad, mas.

QUE NO ES
---------
NO es un modulo de percepcion. No elige el target, no toca la mascara, no toca
el esqueleto. Consume el dict que la candidata YA devuelve y produce un numero.
Es puro: misma entrada, misma salida, sin estado.

POR QUE d_eje NO BLOQUEA EL CALCULO, Y POR QUE IGUAL IMPORTA
-----------------------------------------------------------
`d_eje` -la distancia del eje de rotacion al punto del piso de la fila 119- esta
sin medir y tiene suspendido a T4. Pure pursuit lo necesita de frente, porque el
bearing al target se toma DESDE el eje de rotacion.

Las cantidades que calcula este modulo NO lo necesitan: `psi` es una direccion
-invariante a una traslacion en Z- y `e` es una coordenada X en una fila fija.
Por eso esto se pudo escribir con la Pi apagada.

PERO -y la primera version de este archivo decia "d_eje no importa", que es
demasiado fuerte- lo que se calcula NO es el cross-track canonico. El de
Stanley se toma en el eje del vehiculo; el de aca, en la fila 119. Los dos
difieren en

    d_eje * sin(psi)

que se anula solo con el camino paralelo al robot. Con el `|psi|` que este
sistema tiene de mediana -unos 45 grados- el factor es 0,71: el sesgo es del
mismo orden que `d_eje`. O sea que `e` es un PROXY del cross-track, bueno en
recta y peor cuanto mas dobla, y medir `d_eje` sigue haciendo falta para saber
cuanto vale ese "peor".

LO QUE SIGUE SIN CALIBRAR, Y SE REPORTA EN BANDA
------------------------------------------------
El HFOV. `psi` en grados verdaderos depende de el, asi que todo va para
45 / 60 / 75 y si el veredicto cambia de signo adentro de esa banda, no hay
conclusion.

`v_h = 9,0` SI esta medido: `birdeye.py`, R2 0,982-0,999 en 9 de 11 videos.
"""

import math

W, H = 160, 120
CENTER = (W - 1) / 2.0

V_H = 9.0                # fila del horizonte, medida en birdeye.py
FILA_BASE = 119.0        # la fila mas cercana que ve el robot; Z_rel(119) = 1
HFOV_NOMINAL = 60.0
HFOV_BANDA = (45.0, 60.0, 75.0)

# Arco de suelo sobre el que se estima la tangente del camino, en unidades de
# Z_rel (1,0 = tan lejos como la fila 119). Corto a proposito: psi es la
# tangente LOCAL, no el rumbo promedio hasta el lookahead. Se barre en banda.
ARCO_PSI = 0.60
ARCO_PSI_BANDA = (0.30, 0.45, 0.60, 0.90, 1.30)

# Piso de la velocidad normalizada. Coincide con FACTOR_MIN de vision_linea.py:
# la vision nunca manda menos que 0,55 de la base, asi que dividir por algo mas
# chico seria extrapolar fuera del rango que el robot puede recibir.
V_MIN = 0.55


def f_px(hfov=HFOV_NOMINAL):
    """Distancia focal en pixeles para un campo visual horizontal dado."""
    return (W / 2.0) / math.tan(math.radians(hfov / 2.0))


def suelo(u, v, hfov=HFOV_NOMINAL):
    """(X, Z) en el suelo, RELATIVOS: Z(fila 119) = 1,0.

    Modelo de suelo plano validado en birdeye.py:  Z = k/(v - v_h).
    La escala absoluta no se conoce y no hace falta: se absorbe en la ganancia
    `k` de la ley. Lo que si es real es la FORMA, y con ella el hecho de que un
    pixel arriba vale decenas de veces mas suelo que uno abajo.
    """
    Z = (FILA_BASE - V_H) / max(v - V_H, 1e-6)
    X = (u - CENTER) * Z / f_px(hfov)
    return X, Z
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

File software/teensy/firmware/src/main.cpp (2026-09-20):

#include <Wire.h>
#include <Arduino.h>
#include <drivebase.h>
#include <PID.h>
#include <elapsedMillis.h>
#include <Adafruit_Sensor.h>
#include <Adafruit_BNO055.h>
#include "math.h"
#include <Servo.h>
#include <Adafruit_I2CDevice.h>
#include <claw.h>
#include "Adafruit_APDS9960.h"
#include <NewPing.h>
#include <Wire.h>
#include <VL53L0X.h>
#include <telemetria.h>

// ============================================================================
// RescueBot IITA Salta - firmware de competencia del Teensy 4.1 (RCJ Rescue Line 2026). Se flashea
// con `pio run --target upload` (entorno por defecto `competencia`).
//
//   ------------------------------------------------------------------------
//   MAPA DEL ARCHIVO  (en este orden)
//
//     1. PANEL DE CONFIGURACION ....... aca abajo. TODO lo que se toca.
//     2. Estado de la recuperacion de linea y del GAP
//     3. Objetos de hardware: servos, garra, IMU, motores, DriveBase
//     4. Estado global del robot y protocolo con la Raspberry
//     5. Sensores: ultrasonidos, ToF, color (APDS9960)
//     6. Serial con la Raspberry (serialEvent5)
//     7. Primitivas de movimiento: runTime / runAngle / runDistance
//     8. Evacuacion: colores, esquive, finales de carrera
//     9. Anti-atasco (loma de burro) y traccion en rampa
//    10. Telemetria JSON hacia la ESP32
//    11. setup()
//    12. loop()  ->  idle / arranque / lazo de linea / rescate / evacuacion
//
// El entorno `competencia` compila MODO_DIAGNOSTICO=1 (CSV de 200 Hz por USB) y TELEMETRIA=0. El
// movimiento se tuneó con esa carga (~10 % del lazo): cambiarla cambia el comportamiento y obliga a
// volver a probar en pista. La GUI por WiFi está en el entorno `telemetria`.
//
// La Pi manda por Serial5 velocidad, ángulo, código de tarea (green_state) y plateado. La Teensy
// traduce el ángulo a consignas de rueda y ejecuta las maniobras que pide el código de tarea.
//
// Archivos hermanos: lib/drivebase (steer y PID por rueda), lib/claw (garra), src/diagnostico.h
// (registrador CSV; entra en `competencia`), platformio.ini (entornos).
//
// ============================================================================


// ############################################################################
// 1. PANEL DE CONFIGURACION. Cada constante va detrás de #ifndef y se puede pisar con -D desde
// platformio.ini.
// ############################################################################

// ----------------------------------------------------------------------------
// 1.1 SEGUIMIENTO DE LINEA (case 7):
//   angle 0..180 -> steer = (angle-90)/90 -> steerCmd = constrain(steer*LINE_STEER_GAIN, -1, 1)
//   -> absSteer = |steerCmd| -> rot = absSteer^LINE_ROT_EXP
//   Si absSteer >= LINE_FRENO_STEER: steerFrenoDelantero(LINE_FRENO_VEL, ±rot);
//   si no: steer(vel*LINE_RECTA_FACTOR, ±rot), vel = rampa cuadrática base -> LINE_PIVOT_SPEED.
// Radio R = b_eff*(1-rot)/(2*rot), b_eff = 20,9 cm: la velocidad no cierra la curva, solo `rot`.
// Medido: R_real ≈ 1,15 x R_pedido.
// ----------------------------------------------------------------------------

// Ganancia del ángulo antes de calcular rot. 1.0 = sin cambio (con 1.8 empeoró el cabeceo
// y satura antes).
#ifndef LINE_STEER_GAIN
#define LINE_STEER_GAIN 1.0
#endif

// rot = absSteer^LINE_ROT_EXP. Es la palanca del radio: más chico = más agresivo; 1.0
// = rampa lineal.
#ifndef LINE_ROT_EXP
#define LINE_ROT_EXP 0.85
#endif

// 1.01 = pivote con histéresis APAGADO (absSteer nunca pasa de 1.0). Está apagado a propósito: con
// el pivote, el robot pasaba el 29,7 % del tiempo girando sin avanzar (7,8 % sin él). Para
// prenderlo: 0.60.
#ifndef LINE_PIVOTE_ENTRA
#define LINE_PIVOTE_ENTRA 1.01
#endif

// Umbral de salida del pivote (solo si LINE_PIVOTE_ENTRA <= 1.0). La histéresis evita
// picotear el giro.
#ifndef LINE_PIVOTE_SALE
#define LINE_PIVOTE_SALE 0.15
#endif

// Tiempo que debe sostenerse la alineación para soltar el pivote. Las rachas alineadas duran
// 50-75 ms: con >= 300 ms solo sale por LINE_PIVOTE_MAX_MS.
#ifndef LINE_PIVOTE_CONFIRMA_MS
#define LINE_PIVOTE_CONFIRMA_MS 0UL
#endif

// Tope del pivote. A ~39 grados/s, 90 grados cuestan ~2,3 s: no hay margen.
#ifndef LINE_PIVOTE_MAX_MS
#define LINE_PIVOTE_MAX_MS 2500UL
#endif

// Techo (rpm) de la rampa cuadrática de velocidad, solo para absSteer < LINE_FRENO_STEER. Con
// LINE_FRENO_STEER=0.70 la rampa llega a k^2 ≈ 0,58 (~45 rpm): este valor no se alcanza. La curva
// cerrada usa LINE_FRENO_VEL.
#ifndef LINE_PIVOT_SPEED
#define LINE_PIVOT_SPEED 50
#endif

// Factor de velocidad fuera de la curva cerrada (1.0 = sin cambio). No cierra el radio: da tiempo
// de reacción (más frames de cámara por cm).
#ifndef LINE_RECTA_FACTOR
#define LINE_RECTA_FACTOR 0.8
#endif
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

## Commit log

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2026-08-19 feat(teensy): entornos de diagnostico y dos fixes condicionales de curva
    Agrega 8 entornos de PlatformIO ademas del de competencia, todos sobre el
    MISMO src/main.cpp (una copia divergiria y dejaria de describir al robot que
    compite). Se separan solo por -D:
    banco_barrido / _fix barrido de rotation y velocidad, sin pista ni vision
    diagnostico registrador CSV 45 columnas a 200 Hz por USB
    diagnostico_lazo/_fix idem + fixes, para atribuir cada diferencia
    diagnostico_suelto CSV por Serial8 (sin cable que tironee del chasis)
    diagnostico_full USB 200 Hz + WiFi 10 Hz en paralelo, por redundancia
    competencia_fix el robot andando con los fixes, sin registrad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
    [main.cpp]
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2026-08-20 fix(teensy): restaurar plateadoDetectado, quedo cableado a false
    Las dos ramas de deteccion de plateado ponian `plateadoDetectado = false` y la
    variable se inicializa en false, asi que el `if (plateadoDetectado) action = 2`
    de mas abajo era CODIGO MUERTO. En afeb995 las dos ramas ponian `true`.
    Efecto: la Teensy perdio su disparo local de zona de evacuacion y quedo
    dependiendo 100% de que la camara mandara silver_line == 1. El Serial5.write(241)
    seguia saliendo, asi que desde afuera no se notaba nada.
    No esta detras de ningun #if: entra en el binario de competencia. No tiene
    nada que ver con el diagnostico de curvas; se colo en esas sesiones.
    [main.cpp]
2026-08-20 fix(rpi): proteger el import de telemetria_vision con un objeto nulo
    telemetria_vision.py promete en su docstring que NUNCA levanta una excepcion
    hacia el lazo de vision, y sus metodos lo cumplen. El import no estaba
    cubierto.
    Importa porque lo que corre en la Raspberry es un archivo suelto del Desktop,
    no el del repo: alcanzaba con copiar Main.py y olvidarse de copiar
    telemetria_vision.py al lado para que LA VISION NO ARRANCARA. Justo el sabado,
    justo cuando se instala el enganche.
    Ahora, si el modulo no esta, se usa un objeto nulo, se avisa por consola y el
    robot corre igual sin telemetria de vision. Un registro no puede voltear una
    corrida.
    [Main.py]
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2026-08-22 feat(teensy): banco_pines, tester de las lineas de encoder
    Nace de un problema real: el 2026-08-22, con el robot en la mesa, el
    registrador mostraba `raw` congelado en 4,4,5,4 y ninguna de las cuatro ruedas
    contaba un flanco. "raw no se mueve" tiene tres causas que se arreglan en
    lugares distintos y el CSV no las separa:
    pin fijo en 0 -> no llega señal (motor sin alimentacion, salida muerta)
    pin flotando -> cable al aire
    pin cambia al girar -> la señal llega y el problema es de firmware
    Este sketch las separa. Mide cada pin de dos maneras a proposito -sin pull-up y
    con el pull-up interno- y cuenta flancos por muestreo rapido, SIN interrupciones,
    para no depender de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
    [pines.cpp]
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2026-08-22 fix(teensy): el timeout de los ToF se configuraba DESPUES del init que lo necesita
    left_tof.init(); <- corria con io_timeout = 0
    left_tof.setTimeout(500); <- una linea tarde
    El constructor de VL53L0X deja io_timeout(0) (lib/VL53L0X/VL53L0X.cpp:40) y la
    guarda de la libreria es
    #define checkTimeoutExpired() (io_timeout > 0 && ...) // VL53L0X.cpp:19
    que con io_timeout == 0 devuelve false SIEMPRE por el cortocircuito. O sea que
    durante todo init() los tres while que esperan al sensor -getSpadInfo en :894 y
    las dos performSingleRefCalibration en :1023- tienen adentro un `if
    (checkTimeoutExpired()) return false;` que es CODIGO MUERTO. Son bucles sin
    salida: tres por sens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
    [main.cpp]
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2026-08-22 fix(teensy): acotar el reset del BNO, y el perfil de velocidad de la curva
    DOS COSAS, las dos medidas en pista el 2026-08-22.
    1) EL CUELGUE DEL BNO, que costo cuatro arranques en el dia.
    Adafruit_BNO055::begin() manda un reset por software al sensor y despues:
    while (read8(BNO055_CHIP_ID_ADDR) != BNO055_ID) { delay(10); }
    Sin salida. Si el sensor no vuelve del reset -pasa, y es intermitente-
    begin() no retorna nunca y setup() queda colgado: LED apagado, puerto mudo.
    El manejo de "el BNO no responde" que ya tenia el firmware
    (handleBnoInitFailure y el #if MODO_BANCO no fatal) solo corre si begin()
    DEVUELVE, asi que no podia ayudar: el while esta antes de cualquier re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
    [i2c.cpp, main.cpp]
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2026-08-22 fix(rpi): el parche buscaba Main.py y en la Raspberry se llama main.py
    En Linux las mayusculas importan. El archivo del repo es Main.py y el que corre
    en la Pi es main.py, asi que el parche fallaba por una letra:
    *** No encuentro Main.py al lado de este script
    Ahora busca cualquier variante de main.py en su propia carpeta, y ademas acepta
    una ruta explicita como argumento por si esta en otro lado.
    [parche_planner.py]
2026-08-22 fix(rpi): el video del parche no se cerraba, y no mostraba la mascara
    Primera corrida con el planner manejando, 2026-08-22: [PLANNER] encendido,
    grabo, y el robot SE SALE MAS que con el metodo viejo. Ademas [LINE-FPS] cayo
    de 55 a 34.07, o sea que trazar() cuesta ~11 ms por frame en la Pi (en PC daba
    0,54). Los 390 pasos de Python puro se notan.
    Pero 11 ms a esa velocidad son ~1 mm de recorrido, asi que la latencia sola no
    explica que se salga: el angulo tiene que estar mal. Y sin ver la mascara no se
    puede distinguir "el trazo se fue por donde no habia cinta" de "la mascara no
    vio la cinta", que se arreglan en lugares distintos.
    DOS ARREGLOS:
    1. seguidor_linea.paso() devuelve ahora la ma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
    [parche_planner.py, seguidor_linea.py]
2026-08-22 feat(rpi): modo HIBRIDO, el centroide manda y el trazo entra donde se satura
    Idea de Benjamin, y tiene fundamento: un seguidor de linea necesita DOS errores
    y el atan2 los mezcla en uno solo.
    error LATERAL (cuan corrido estoy de la cinta)
    lo mide bien el CENTROIDE: promedia toda la mascara, es estable y no se
    puede equivocar de rama.
    error de RUMBO (para donde SIGUE la cinta)
    lo mide bien el TRAZO: camina la linea, asi que conserva su orientacion.
    Cuando la cinta queda HORIZONTAL en el ROI -o sea, en la curva cerrada-
    y_resultant tiende a 0 y el centroide salta a +-90 sin gradacion: sabe que el
    robot esta mal parado pero NO para donde ir. Medido en pista el 2026-08-2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
    [parche_planner.py]
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2026-08-22 fix(rpi): sacar la metrica de "perspectiva", clasificaba al reves
    Media ancho_lejos / ancho_cerca suponiendo que una cinta que se aleja se
    estrecha. Validada contra frames del video del 2026-08-22 con la respuesta
    conocida a ojo, dio 3 de 5 AL REVES:
    #856 trapecio claro (perspectiva) -> 0,97 la llamaba MANCHA
    #570 banda evidente (mancha) -> 0,14 la llamaba perspectiva
    #666 banda evidente (mancha) -> 0,17 la llamaba perspectiva
    #1046 banda evidente (mancha) -> 0,27 la llamaba perspectiva
    Se saca en vez de dejarla adentro. Una metrica que no se valido contra la
    realidad es peor que no tener metrica, porque se le cree. Ya se habia dado un
    "55% de los frames s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
    [medir_camara.py]
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2026-08-23 fix(rpi): el termino de anticipacion miraba negro que no era la linea
    Observacion de Benjamin -"ve basura en el horizonte"- y tenia razon, aunque no
    del todo por donde parecia: lo que cae en la banda de anticipacion no es el
    salon, son OTROS TRAMOS NEGROS DE LA PISTA (otra cinta cruzando, juntas del
    piso) que no estan conectados con la linea que el robot esta siguiendo.
    _solo_mi_linea() deja unicamente la mancha que toca al robot, por conectividad.
    Cuesta 0,09 ms por frame.
    MEDIDO, y hay que decir el tamaño real del efecto:
    frames con basura presente en la banda 38,4 %
    pero frames donde le cambia el SIGNO a e_lejos 1,2 %
    frames donde lo corrige mas de 0,3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
    [parche_planner.py]
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2026-08-23 fix: el verde no giraba por un re-chequeo tardio, y la recuperacion no se activaba
    DOS BUGS DISTINTOS, los dos reportados por Benjamin mirando el robot.
    1) EL VERDE. "Veo que disminuye la velocidad pero no hace el runAngle."
    El case 6 y el case 5 del firmware hacian:
    runTime(20, FORWARD, 0, 800); avanzar 800 ms <- la bajada de velocidad
    serialEvent5(); releer el serial
    if (green_state == 1) runAngle(...);
    Despues de avanzar 800 ms el cuadrado verde YA SALIO del campo de la camara,
    asi que la Raspberry manda green_state = 0, el if falla y el giro no se
    ejecuta nunca. La decision YA se habia tomado al poner action = 6; volver a
    pregunt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
    [main.cpp, parche_planner.py]
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2026-08-23 feat: al perder la linea, RETROCEDER un paso y volver a mirar
    Idea de Benjamin, y es la correcta: "que el main retroceda y despues gire hasta
    alinearse con la linea y recien retomar".
    POR QUE RETROCEDER Y NO BUSCAR GIRANDO. La linea no desaparece por casualidad:
    desaparece porque el robot se paso. Un segundo antes la tenia abajo. Retroceder
    rehace el camino y la devuelve al cuadro; girar a ciegas puede alejarlo mas.
    Y el "alinearse" sale gratis: apenas la linea reaparece -aunque sea pegada a un
    borde- el control normal gira hacia ella solo. No hace falta una maniobra de
    alineacion aparte.
    COMO SE HIZO, y por que asi:
    - No se puede señalizar por el byte del angulo: SERIAL_MAX_ANGLE = 180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
    [main.cpp, parche_planner.py]
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2026-08-23 fix(teensy): el registrador no drenaba en idle, y eso hizo diagnosticar mal
    El lazo de espera con el switch apagado llamaba a enviarTelemetria() y a
    delayTelemetria() pero NUNCA a DIAG_TICK(). Con el switch en off el CSV no sale
    y el puerto queda MUDO, que es exactamente el sintoma de un setup() colgado.
    CONSECUENCIA REAL, el 2026-08-22: se diagnostico TRES VECES "la placa no
    arranco" cuando la placa estaba perfecta, y se le dijo a Benjamin que flasheos
    que SI habian entrado no habian entrado. Perdio tiempo probando en pista
    creyendo que corria un binario viejo.
    Es el mismo bug que el equipo ya habia arreglado una vez -"el registrador
    grababa cero muestras durante el seguimiento de linea,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
    [main.cpp]
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2026-08-23 fix(rpi): el control corregia POSICION y no RUMBO, y por eso quedaba chueco
    Observacion de Benjamin en pista: "despues de un giro no se reacomoda con el
    centro de la linea y queda chueco hasta terminar con algun giro donde la
    pierde". Medido sobre hist.avi y es exactamente eso:
    frames con la linea CENTRADA (|pos| < 12 px) 40 %
    de esos, con el RUMBO torcido (>20 px) 57 %
    error de rumbo mediano estando centrado 28,6 px
    O sea que el robot se para sobre la linea APUNTANDO PARA OTRO LADO, y desde ahi
    se vuelve a ir. Un seguidor necesita DOS errores y el atan2 los mezcla en uno:
    cuando el de posicion es cero el angulo es chico, asi que el control no hace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
    [main.cpp, parche_planner.py]
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2026-08-23 docs(rpi): versionar el main.py real de la Pi, y el bug que esconde
    HIPOTESIS QUE PRUEBA: ninguna. Es la precondicion para probar cualquier cosa
    sobre vision. Hasta ahora el codigo que generaba los datos no estaba en git, asi
    que ninguna conclusion de vision era reproducible.
    QUE CAMBIO: se agrega la foto del ~/Desktop/main.py de la Raspberry tal como
    estaba el 22-ago, recuperada del transcripto de la sesion de trabajo. No
    reemplaza a nada: Main.py (mayuscula) es otra version, mas vieja, con el recorte
    en la fila 55 y una rutina de linea perdida que esta NO tiene. Por eso el nombre
    lleva fecha -y porque en Windows main.py y Main.py colisionarian-.
    QUE SE VERIFICO: que este es el archivo qu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
    [main_rpi_2026-08-22.py]
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2026-08-23 feat(teensy): las constantes del case 7 salen en la procedencia y se barren por build_flags
    HIPOTESIS QUE PRUEBA: ninguna por si misma. Es la precondicion para atribuir
    cualquier diferencia entre corridas.
    EL PROBLEMA: las constantes del seguimiento de linea estaban declaradas DENTRO
    del case 7, y eso costo el dia entero del 22-ago. diagProcedencia() emitia hz,
    ticks, fix_lazo, fix_curva, ks, kv, piso, anticoast, puerto, sin_imu, lazo y
    commit -y CERO constantes del case 7-. Se grabaron diez CSV y despues no se pudo
    atribuir ninguna diferencia a ninguna constante: dos corridas con ganancias
    distintas eran indistinguibles en el archivo. Ademas, barrer un valor obligaba a
    editar, recompilar y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
    [main.cpp]
2026-08-23 fix(teensy): el signo del pivote no se puede dar vuelta antes de T_min
    HIPOTESIS QUE PRUEBA: que el robot no junta grados en la curva porque cambia de
    idea antes de que el motor llegue a regimen. Es la unica hipotesis que quedo en
    pie despues de tres investigaciones y tres refutaciones adversariales.
    EL NUMERO QUE LA SOSTIENE, medido sobre las 6 corridas de pista (369 tramos de
    linetrack con |rot| >= 0,95 y signo constante):
    duracion p50 0,190 s
    grados entregados p50 4,9
    tramos que llegaron a 45 grados 1 de 369
    tramos que llegaron a 90 grados 0 de 369
    tramos consecutivos que CAMBIAN de signo 32% a 87%
    Y al mismo tiem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
    [main.cpp]
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2026-08-23 fix: el fps de 20 estaba escrito a mano y inflo 1,67x todos los tiempos
    HIPOTESIS QUE PRUEBA: ninguna. Corrige una constante equivocada que contamino
    todos los numeros en segundos publicados hasta ayer.
    EL PROBLEMA: el AVI DECLARA 20 fps porque el VideoWriter recibe ese numero fijo.
    El lazo corre a ~33. Todo el analisis dividio por 20, asi que cada duracion en
    segundos salio inflada 1,67x: "3,7 segundos sin linea" eran 2,2.
    QUE CAMBIA:
    - analizar_corrida.py deja de dividir por 20,0. Saca el fps del LOG POR FRAME de
    la corrida cuando existe -numero de frame y time.monotonic(), sin suponer
    nada- y si no hay log usa una constante documentada, forzable con FPS=xx.
    - la tabla de base se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
    [analizar_corrida.py, parche_planner.py]
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2026-08-23 fix: los tres bloqueantes que encontro la revision independiente
    Tres revisores independientes miraron los commits de la noche. Encontraron tres
    bloqueantes, los tres reales, y los tres los introduje yo. Verificados con
    mediciones propias antes de aceptarlos.
    BLOQUEANTE 1 - LINE_PIVOTE_CONFIRMA_MS=300 se iba a flashear por primera vez.
    Al poner competencia_fix por defecto se enciende FIX_CURVA_CONTINUA, y adentro
    vive un pivote que exige 300 ms de alineacion SOSTENIDA para soltar. Ese valor
    nunca corrio en el robot. Medido sobre los 6 CSV: las rachas continuas de
    absSteer <= 0,15 duran 50-75 ms de mediana y SOLO EL 1,2-7,7% LLEGA A 300 ms, o
    sea que la salida por alineacion es inalcanzable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
    [analizar_corrida.py, main.cpp, parche_planner.py]
2026-08-23 fix: el resto de la revision, y el criterio PASS estaba medido sobre una poblacion que ya no existe
    Lo mas importante de este commit es que corrige el numero con el que se iba a
    decidir el sabado.
    EL CRITERIO PASS ESTABA MAL. Los 0,190 s de duracion de tramo salen de las seis
    corridas del 22-ago, y NINGUNA tenia el latch de pivote encendido: verificado que
    s_en_pivote no existe en los commits que las produjeron. Sin latch, rot sigue a
    absSteer y el tramo se corta apenas baja el angulo. Medido: el 79,9% de los
    tramos termina por SALIR DE LA BANDA y solo el 20,1% por cambio de signo -y eso
    depende del latch: el arbol historico da 0% de cambios de signo y la corrida con
    latch da 52%-.
    Encende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
    [main.cpp]
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2026-08-23 fix: use un modelo teniendo la telemetria al lado, y el dwell queda muerto
    UN ERROR MIO, detectado por un analisis externo. Dije que en el frame 1374 el
    pivote soltaba; el CSV dice rot=-1,000, o sea enganchado a fondo. Alimente un
    MODELO del case 7 con el rxsteer real en vez de leer la columna `rot`, que estaba
    en el mismo archivo.
    La validacion que nunca hice, sobre 961 frames: el modelo coincide 92% en el
    estado de pivote pero cuenta 36 sueltas contra 55 reales, o sea que subestima un
    35%. Todas las estadisticas de "224 sueltas" y "88% por alineacion" salian de ahi.
    NUMEROS CORREGIDOS con rot real, 295 episodios de 6 corridas:
    duracion p50 210 ms (yo habia dicho 428)
    grados p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
    [main.cpp]
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2026-08-23 feat(rpi): H8 cae. El peso de continuidad no es la palanca del salto
    Con H6a ganando -las ramas son topologia real-, el problema es elegir por cual
    rama sigue la trayectoria, y eso ya existe en el score de path_target
    (nuevo_code_v2.py:289-298), donde la continuidad pesa 0,10.
    H8: ese 0,10 es lo que deja que la eleccion se vaya de rama.
    Barrido de 0,0 a 2,0, con autovalidacion 401/401 de que la copia parametrizada
    reproduce el original con w = 0,10:
    w disp s/aut huecos >24px inv suav controles
    0,00 93,72 % 873 284 251 394 1,91 PASA
    0,10 93,76 % 867 278 246 392 1,91 PASA
    0,25 93,77 % 866 277 245 392 1,80 PASA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
    [continuidad.py]
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2026-08-24 feat(rpi): banco de runtime para la candidata. Falta correrlo EN LA PI
    P0 del traspaso: la candidata V1 RC (SinBranch = V2+Spatial) hace skeletonize +
    grafo + Dijkstra por frame, los autonomos son 100/3 fps y nunca medimos eso en
    la Raspberry. Descubrirlo el sabado cuesta una de las dos sesiones fisicas.
    La Pi NO estaba accesible (ni ping ni puerto 22 en toda la 192.168.0.0/24, y
    tampoco en las entradas viejas de ~/.ssh/config). Por eso aca NO hay ningun
    numero de Pi: hay un banco reproducible y un unico comando para correrlo.
    bench_runtime.py mide 19 etapas con tiempo EXCLUSIVO y contabilidad de pila,
    asi que no hay doble conteo cuando una etapa llama a otra. Instrumenta por
    espias revers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
    [bench_runtime.py]
2026-08-24 fix(rpi): la medida de camara ocultaba la edad del frame. ChatGPT tenia razon
    Correccion metodologica de ChatGPT en #138 contra `9c460fc`. Mi medir_camara
    usaba cv2.VideoCapture.read() SINCRONO, que no es el patron de produccion, y
    sumaba captura+algoritmo en un solo numero. Con un hilo de captura asincrono eso
    OCULTA LA EDAD DEL FRAME: el consumidor recibe al instante una imagen capturada
    N periodos antes, el throughput se ve excelente y la latencia sensor->actuador
    es peor.
    Ahora son TRES numeros que no se mezclan: T_algorithm, T_frame_age (timestamp
    monotonico estampado por el hilo apenas V4L2 entrega el frame, con numero de
    secuencia) y T_observed = age+alg. T_observed NO se llama foton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
    [bench_runtime.py]
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2026-08-24 feat(rpi): auditoria fisica. La cinematica NO es la causa; el lazo mezcla posicion y rumbo
    Se refutaron H5, H6, H6b, H8, H9, H9-GATE y H10. Todas eran hipotesis sobre la
    PERCEPCION. Cuando cae el arbol entero conviene dudar del marco, no de las hojas.
    Tres mediciones fisicas que nunca habiamos hecho.
    A) FACTIBILIDAD CINEMATICA - REFUTADA POR SUS PROPIOS CONTROLES
    Hipotesis: si la pista exige mas de los 39 grados/s que da el robot, ningun
    arreglo de vision salva la curva. Se estimo el yaw real por correlacion de fase
    sobre el fondo lejano, que no depende de la candidata.
    tramo p50 p90 % >39/s
    hist_falla 23,0 54,7 31,5 %
    hist_exito 33,5 77,7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
    [auditoria_fisica.py]
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2026-08-24 fix(teensy): sacar los sensores bloqueantes del lazo de linea. PENDIENTE DE BANCO
    El `while (rutina == "linea")` llamaba a leer_tof() y leer_ultrasonidos() en CADA
    vuelta, y las dos son bloqueantes:
    leer_tof() el VL53L0X en modo continuo hace ESPERA ACTIVA hasta
    tener muestra nueva. Nunca se llama
    setMeasurementTimingBudget(), asi que queda el
    presupuesto por defecto del chip, ~33 ms.
    leer_ultrasonidos() tres ping_cm() de NewPing, hasta ~8,7 ms cada uno con
    MAX_DISTANCE=150.
    Medido sobre 7673 periodos de lazo en 6 corridas: p50 = 30 ms, con un segundo
    modo en 65 ms. Una distribucion a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
    [main.cpp]
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2026-08-25 feat(rpi): detector de curva cerrada. 84 % de las curvas con 1 segundo de aviso
    EL OBJETIVO, dicho por Benjamin: el robot se sale en las curvas cerradas y eso
    tiene que dejar de pasar.
    LO QUE YA HABIA, y que no sabiamos: la Teensy YA FRENA EN CURVA.
    double k = constrain(absSteer / LINE_PIVOT_STEER, 0.0, 1.0);
    int vel = velocidadAjustada + k*k*(LINE_PIVOT_SPEED - velocidadAjustada);
    40 en recta, 42 a mitad de curva, 50 en pivote, con rampa cuadratica. El propio
    comentario del firmware dice que lo midieron en pista el 22-ago: "en la zona
    intermedia la corrida MAS LENTA rindio mejor".
    ENTONCES EL PROBLEMA NO ES QUE NO FRENE: ES QUE FRENA TARDE. `absSteer` sube
    cuando la curva ya est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
    [curva_cerrada.py]
2026-08-25 fix(rpi): mis controles positivos eran mas debiles de lo que crei, y mi gate nuevo estaba mal
    La auditoria de V1 -25 agentes, 6 hallazgos confirmados de 20- encontro que el
    gate que use en TODOS los A/B de esta investigacion no ve lo que dice ver. El
    ejemplo es concreto: con una variante de slew K=20, hist da 100/100, lineal da
    73/73, el maximo queda en +89,4, y sin embargo el steer MINIMO dentro de lineal
    f800-872 se desploma de +85,6 a -64,7. Una inversion de signo completa adentro
    del control positivo, y el gate no dijo nada.
    Escribi un gate endurecido que exigia cero inversiones y rango [+80,+90]. Con
    ese gate, BASE fallaba (3 inversiones), CAMINO+MONO fallaba (1) y V1 pasaba
    limpia. Es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
    [sentido_controles.py]
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2026-08-25 feat: lazo de velocidad cerrado. La vision anticipa la curva y la Teensy le hace caso
    EL OBJETIVO: que el robot deje de salirse en las curvas cerradas.
    LO QUE YA HABIA. La Teensy frena en curva desde hace rato:
    k = constrain(absSteer / LINE_PIVOT_STEER, 0, 1)
    vel = velocidadAjustada + k*k*(LINE_PIVOT_SPEED - velocidadAjustada)
    comentario del firmware dice que se midio en pista el 22-ago.
    EL PROBLEMA NO ERA QUE NO FRENARA: ERA QUE FRENABA TARDE. `absSteer` sube cuando
    la curva ya esta encima, porque el steer sale de un target a lookahead fijo.
    Y EL CANAL PARA ARREGLARLO YA EXISTIA Y ESTABA IGNORADO. E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
    [Main.py, main.cpp]
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2026-08-25 fix: watchdog de comunicacion, y un bug de integracion que introduje yo
    DOS COSAS, y la segunda es un error mio.
    1) WATCHDOG DE COMUNICACION EN LA TEENSY
    No habia ninguno. `grep 'WDT|watchdog' src/main.cpp` daba cero. `g_last_rx_ms` se
    calculaba y se usaba SOLO en telemetria: ninguna rama apagaba los motores por
    comando rancio.
    Medido en una corrida grabada: 49 % de las muestras con mas de 1 s sin trama
    nueva, ventana continua de 17,1 s sobre el mismo comando, maximo 27,0 s. Si la
    Raspberry se cuelga en pista, la Teensy ejecuta la ultima orden indefinidamente y
    el robot se va dando vueltas hasta que lo levanta el arbitro.
    Ahora: si pasan mas de 400 ms sin trama valida, frena con
    robot.st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
    [Main.py, main.cpp]
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2026-08-25 feat(rpi): posicion y rumbo separados. Los cinco falsadores sobreviven
    Defecto 3.5.1 del traspaso, el ultimo de los tres del calculo de angulos que
    seguia abierto. La ley de hoy es UN numero -steer = -90*(x_target-CENTER)/(W/2)-
    y mete por ahi dos errores fisicamente distintos, con UNA ganancia, sin ver
    nunca la velocidad. Stanley: delta = psi + arctan(k*e/v).
    LOS CINCO FALSADORES, escritos antes en FALSADOR-STANLEY.md
    F1 max |corr(e,psi)| 0,258 en las 15 celdas (moria a 0,90) VIVE
    F2 max R2(psi ~ x_target) 0,497 en las 15 celdas (moria a 0,90) VIVE
    F3 p90 de discrepancia 34,6 a 40,2 grados en las 15 celdas: supera los
    CINCO umbrales preregistrados 2/5/8/12/20 e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
    [control_psi.py, ley_steer.py]
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

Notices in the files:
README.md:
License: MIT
